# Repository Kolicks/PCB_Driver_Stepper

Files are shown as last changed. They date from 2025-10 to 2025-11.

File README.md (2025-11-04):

# 🌀 PCB_Driver_Stepper
**General Stepper Motor Driver Board**

## 🎬 Demo Video
[▶️ Watch Demo](Test_media/NEMA_Stepper.mp4)

<p align="center">
  <video src="https://github.com/user-attachments/assets/646c0d09-2157-4537-b24f-0206d356a9b6" width="600" controls></video>
  <br>
  <em>Demo NEMA Stepper</em>
</p>

---

## 📘 Overview
**PCB_Driver_Stepper** is a general-purpose stepper motor driver board designed in **KiCad 9**.  
This project was created to explore stepper motor control concepts, test design ideas from friends, and gain real experience with PCB design and STM32 microcontroller integration.  
It also represents my first complete project combining **hardware and STM32 firmware** using **STM32CubeIDE**.

<p align="center">
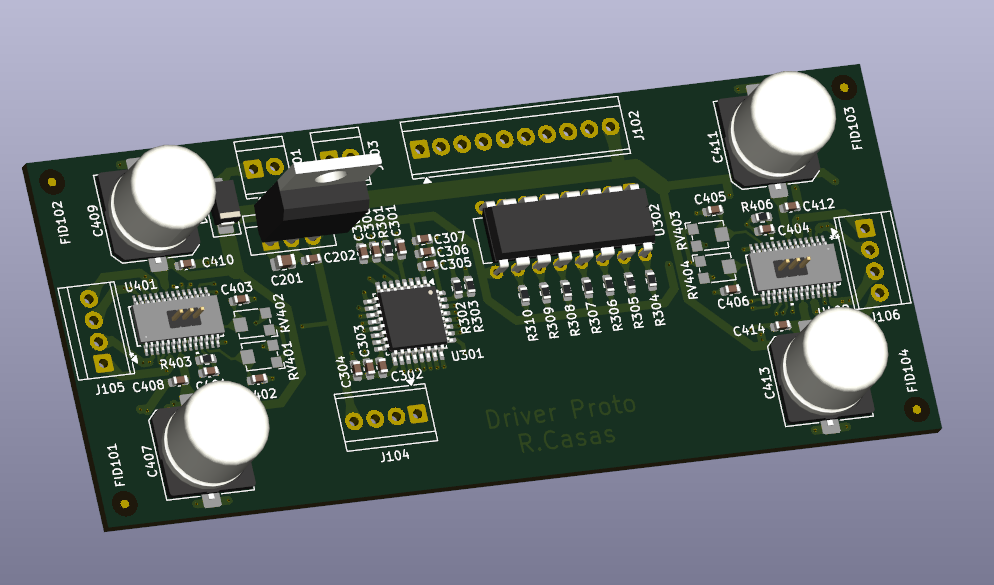
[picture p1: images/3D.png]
3D Render
  
  <br>
  <em>3D render of the finished PCB_Driver_Stepper board</em>
</p>

---

## ⚙️ General Information
- First real **KiCad 9** project.
- Implemented to test and validate several design ideas.
- Tested multiple implementations, including **ULN2002** and different **power dissipation** techniques.
- Designed with **4 layers**, though a **2-layer** version could be achieved.
- Typical **FR4 PCB**, **1.6 mm thickness**, standard prepreg stackup.
- Serves as my first practical integration within **STM32CubeIDE**, using **STM32F030K6T6** as the MCU.

<p align="center">
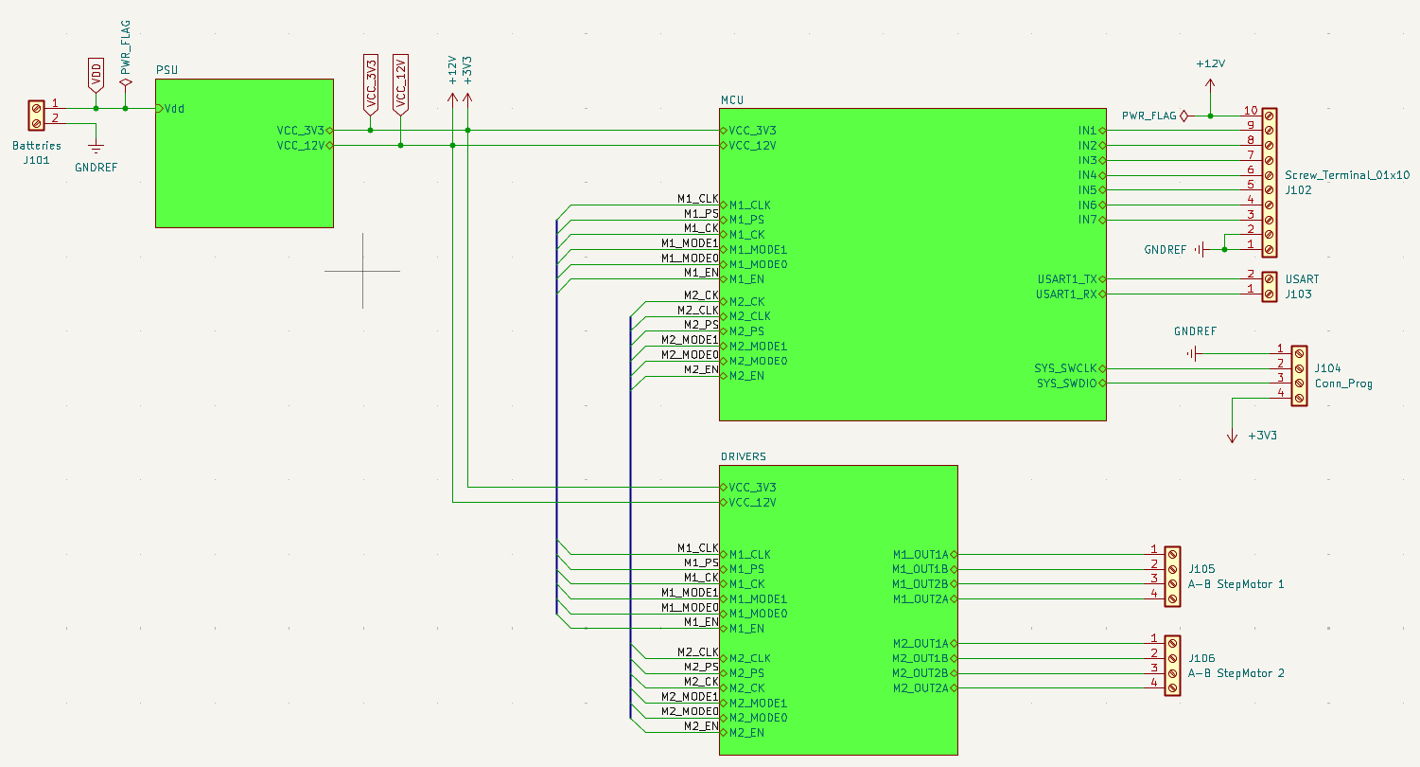
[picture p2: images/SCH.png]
Schematic
  
  <br>
  <em>Schematic, Block diagram (KiCad 9)</em>
</p>

---

## 🔧 Characteristics
- **Fully functional**, fabricated and tested successfully.
- Tested with **STEPPERONLINE NEMA 17** (2A, 59 N·cm) — achieves over **300 RPM** without load.
- Capable of controlling **two stepper motors** simultaneously.
- Supports up to **2 A per motor**, limited by drivers and onboard potentiometers.
- **Operating voltage:** 12 VDC to 24 VDC (ideal at 24 V).
- Requires **external cooling** (top and bottom) for continuous operation (Alimunium or Copper Radiators used in real test).
- Integrated with **ULN2002A** as input mode (tested and working).
- Uses **pin connectors under driver GND pads** to allow hand-soldering.
- Optional **Schottky diodes** for additional protection and power isolation.

<p align="center">
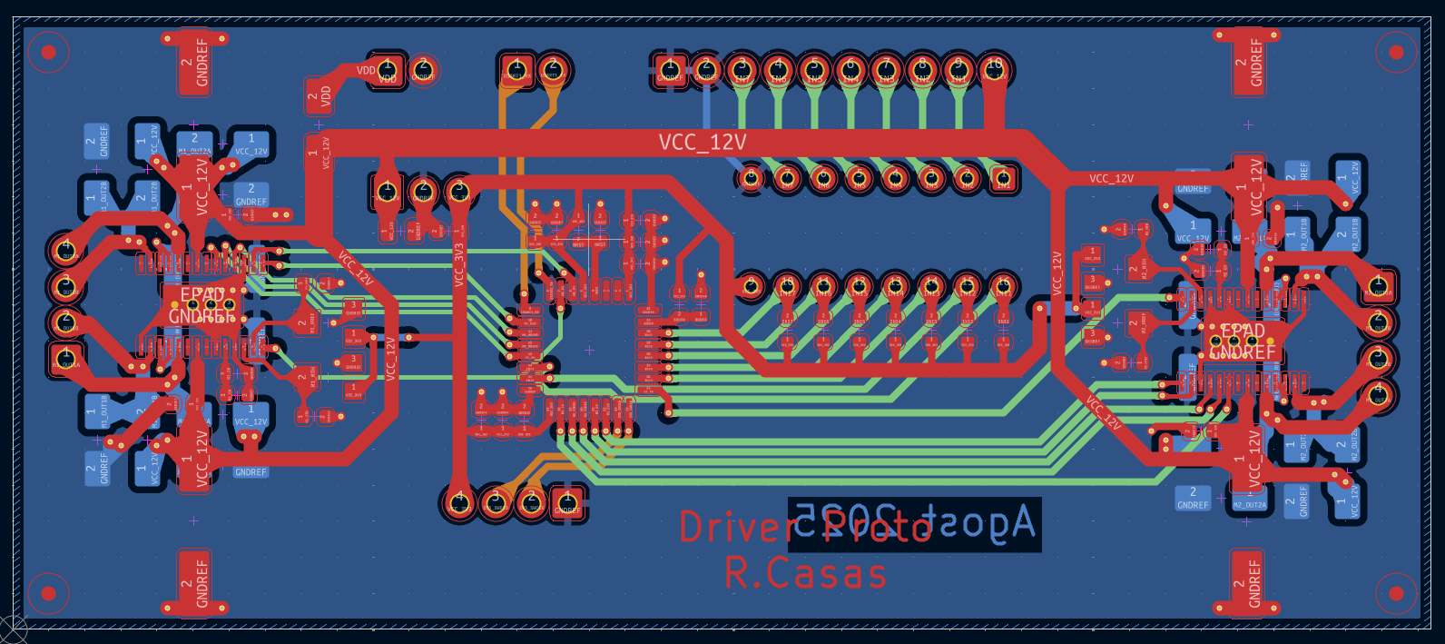
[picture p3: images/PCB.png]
  
  <br>
  <em>PCB layout design</em>
</p>

---

---

## 🔧 Panelization
- **Fully functional**, designed for **JLCPCB** fabrication process.  
- Created as an **exercise in PCB manufacturing and panelization design**.  
- Explored **V-cut (scoring) limitations**, fabrication tolerances, and how they affect mechanical integrity and assembly.  
- Observed potential **issues with scoring alignment and stress concentration** across panelized edges.  
- **Not required for this project**, as the board’s size and simplicity make panelization **unnecessary and potentially inefficient** for performance or cost.  

<p align="center">
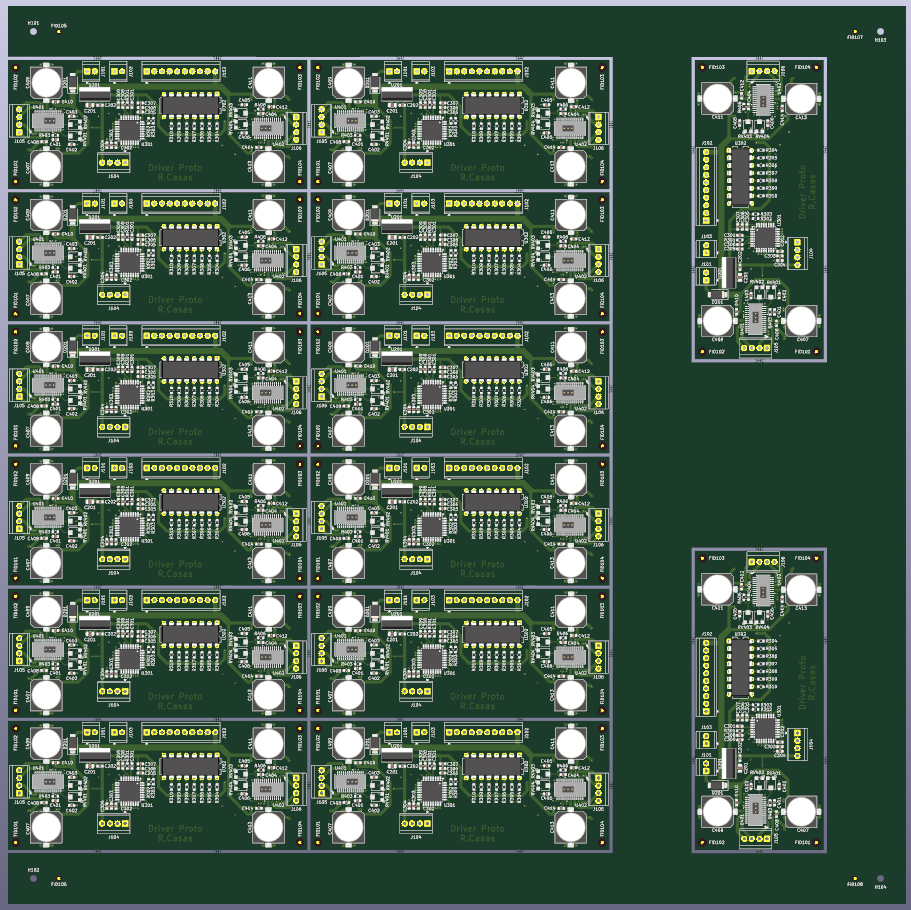
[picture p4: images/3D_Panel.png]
  
  <br>
  <em>Panel layout design</em>
</p>

---

## ⚠️ Known Issues / Notes
- Thermal pads on the **Rsense GND pads** restrict efficient heat dissipation.
- Ideally should maintain a **4-layer design** to ensure proper driver thermal management (as recommended in datasheets).
- Too many bypass Capacitors on the MCU.
- **No status LEDs** (e.g., Power or Fault indicators) currently included — consider adding in future revisions.

---

## 🧩 Files and Structure

<p align="center">
  <a href="https://github.com/Kolicks/PCB_Driver_Stepper" target="_blank">
    
  </a>
</p>

PCB_Driver_Stepper/

├── schematic/ # KiCad schematic files

├── pcb_layout/ # KiCad PCB layout files

├── gerbers/ # Gerber fabrication files

├── images/ # Rendered visuals (3D, SCH, PCB)

├── LICENSE # Hardware license (CERN-OHL-P v2.0)

└── README.md # Project documentation

---

## 📜 License
This hardware design is released under the **CERN Open Hardware License v2 – Permissive (CERN-OHL-P-2.0)**.  
You are free to use, modify, and distribute this design, provided that:
- The license is included with redistributions.
- Proper credit is given to the original author.

More info: https://cern-ohl.web.cern.ch/

---

## 👤 Author
**Project:** PCB_Driver_Stepper  
**Author:** Kolicks  
**Toolchain:** KiCad 9  
**Version:** 9.0  

---

## 🧱 Future Improvements

- **Thermal Design Enhancements:**  
  - Improve **thermal via networks** around driver ICs.  (Done in Panelization)
  - Add **dedicated copper areas** and optional heatsink support for improved temperature control.  (Done in Panelization)

- **User Feedback & Indicators:**  
  - Integrate **status LEDs** for power, enable, and fault signals.  
  - Add a **motor activity indicator** (blinking per step pulse).  

- **Electrical Optimization:**   
  - Consider **thicker copper (2 oz)** for better power handling.  
  - Optimize **Rsense trace routing** to reduce noise coupling.  (Done in Panelization)

- **Mechanical Improvements:**  
  - Adjust mounting hole positions for compatibility with standard enclosures.  
  - Add **labeling and silkscreen clarity** for easier connection identification.  

---

⭐ *If you find this project useful or educational, please consider starring the repository and sharing feedback!*

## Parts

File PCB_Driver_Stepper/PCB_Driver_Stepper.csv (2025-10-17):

Reference | Qty | Value | DNP | Exclude from BOM | Exclude from Board | Footprint | Datasheet
C201 | 1 | 330nF/50V |  |  |  | Capacitor_SMD:C_0805_2012Metric | ~
C202,C302,C303,C305,C306 | 5 | 100nF/10V |  |  |  | Capacitor_SMD:C_0603_1608Metric | ~
C301 | 1 | 100nF |  |  |  | Capacitor_SMD:C_0603_1608Metric | ~
C304,C307,C309 | 3 | 4.7uF/10V |  |  |  | Capacitor_SMD:C_0603_1608Metric | ~
C308 | 1 | 10nF/10V |  |  |  | Capacitor_SMD:C_0603_1608Metric | ~
C401,C402,C403,C404,C405,C406 | 6 | 1000pF/10V |  |  |  | Capacitor_SMD:C_0603_1608Metric | ~
C407,C409,C411,C413 | 4 | 470uF/50V |  |  |  | Capacitor_SMD:C_Elec_10x10.2
C408,C410,C412,C414 | 4 | 100nF/50V |  |  |  | Capacitor_SMD:C_0603_1608Metric | ~
D201 | 1 | 1N4001 |  |  |  | Diode_SMD:D_SMA | http://www.vishay.com/docs/88503/1n4001.pdf
D401,D402,D403,D404,D405,D406,D407,D408,D409,D410,D411,D412,D413,D414,D415,D416 | 16 | SK36A |  |  |  | Diode_SMD:D_SMA | ~
FID101,FID102,FID103,FID104 | 4 | Fiducial |  | Excluded from BOM |  | Fiducial:Fiducial_1mm_Mask3mm | ~
J101 | 1 | Batteries |  |  |  | TerminalBlock_TE-Connectivity:TerminalBlock_TE_282834-2_1x02_P2.54mm_Horizontal | ~
J102 | 1 | Screw_Terminal_01x10 |  |  |  | TerminalBlock_TE-Connectivity:TerminalBlock_TE_1-282834-0_1x10_P2.54mm_Horizontal | ~
J103 | 1 | USART |  |  |  | TerminalBlock_TE-Connectivity:TerminalBlock_TE_282834-2_1x02_P2.54mm_Horizontal | ~
J104 | 1 | Conn_Prog |  |  |  | TerminalBlock_TE-Connectivity:TerminalBlock_TE_282834-4_1x04_P2.54mm_Horizontal | ~
J105 | 1 | A-B StepMotor 1 |  |  |  | TerminalBlock_TE-Connectivity:TerminalBlock_TE_282834-4_1x04_P2.54mm_Horizontal | ~
J106 | 1 | A-B StepMotor 2 |  |  |  | TerminalBlock_TE-Connectivity:TerminalBlock_TE_282834-4_1x04_P2.54mm_Horizontal | ~
J107 | 1 | ThermalDriv1 |  |  |  | Prova_Ricard_Driver_footprint:PinHeader_1x03_P1.27mm_Vertical | ~
J108 | 1 | ThermalDriv2 |  |  |  | Prova_Ricard_Driver_footprint:PinHeader_1x03_P1.27mm_Vertical | ~
R301,R302,R303 | 3 | 100k |  |  |  | Resistor_SMD:R_0603_1608Metric | ~
R304,R305,R306,R307,R308,R309,R310 | 7 | 10k |  |  |  | Resistor_SMD:R_0603_1608Metric | ~
R401,R402,R404,R405 | 4 | 0.25R |  |  |  | Resistor_SMD:R_2512_6332Metric | ~
R403,R406 | 2 | 39k |  |  |  | Resistor_SMD:R_0603_1608Metric | ~
RV401,RV402,RV403,RV404 | 4 | R_Potentiometer |  |  |  | Potentiometer_SMD:Potentiometer_Bourns_TC33X_Vertical | ~
U201 | 1 | LM7833_TO220 |  |  |  | Package_TO_SOT_THT:TO-220-3_Vertical | https://www.onsemi.cn/PowerSolutions/document/MC7800-D.PDF
U301 | 1 | STM32F030K6Tx |  |  |  | Package_QFP:LQFP-32_7x7mm_P0.8mm | https://www.st.com/resource/en/datasheet/stm32f030k6.pdf
U302 | 1 | ULN2002A |  |  |  | Package_DIP:DIP-16_W7.62mm | http://www.ti.com/lit/ds/symlink/uln2003a.pdf
U401,U402 | 2 | BD63521EFV-E2 |  |  |  | HTSSOP-B28_ROM:HTSSOP-B28_ROM | BD63521EFV-E2

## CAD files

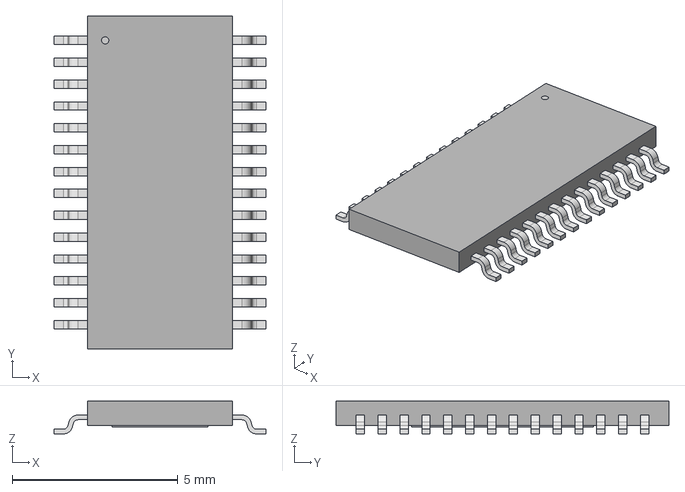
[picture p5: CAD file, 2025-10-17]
PCB_Driver_Stepper/Symbol_Footprint/MBRS360T3G/HTSSOP-B28_ROM.step
6.40 x 10.1 x 0.993 mm

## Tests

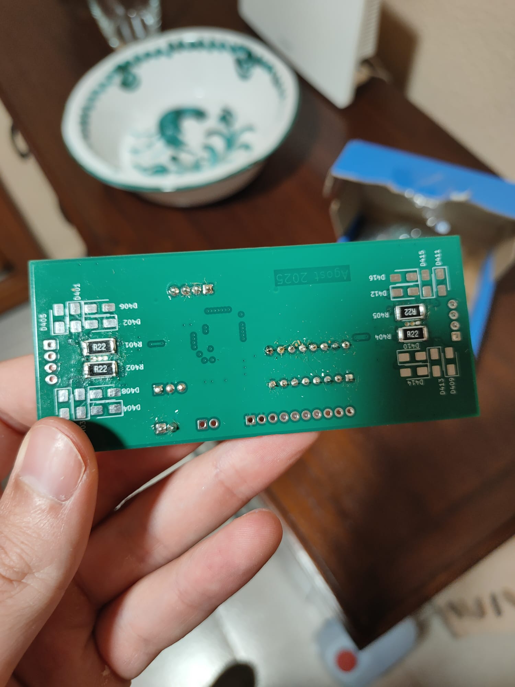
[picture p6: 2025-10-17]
Test_media/Bottom_view.jpeg

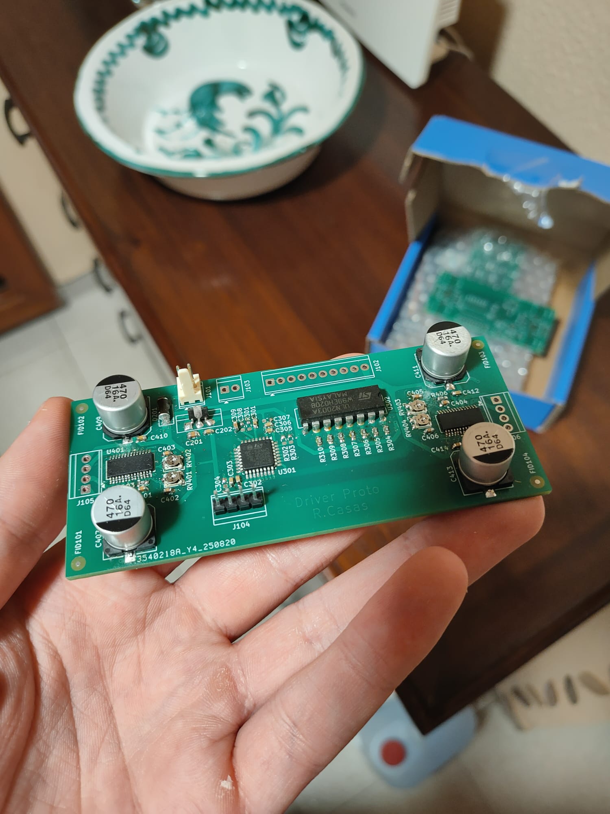
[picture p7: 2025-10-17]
Test_media/TOP_view.jpeg

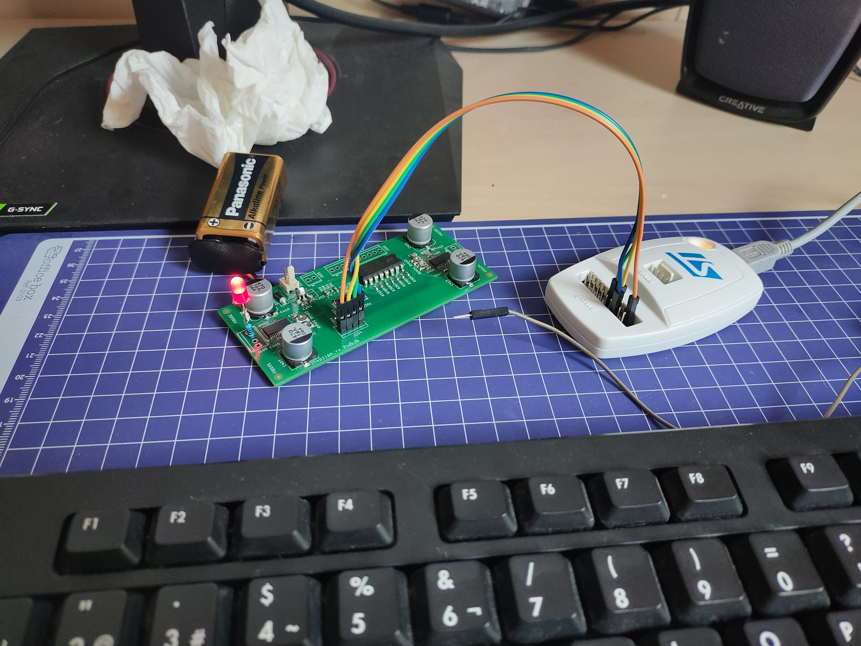
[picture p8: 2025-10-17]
Test_media/Programming.jpeg

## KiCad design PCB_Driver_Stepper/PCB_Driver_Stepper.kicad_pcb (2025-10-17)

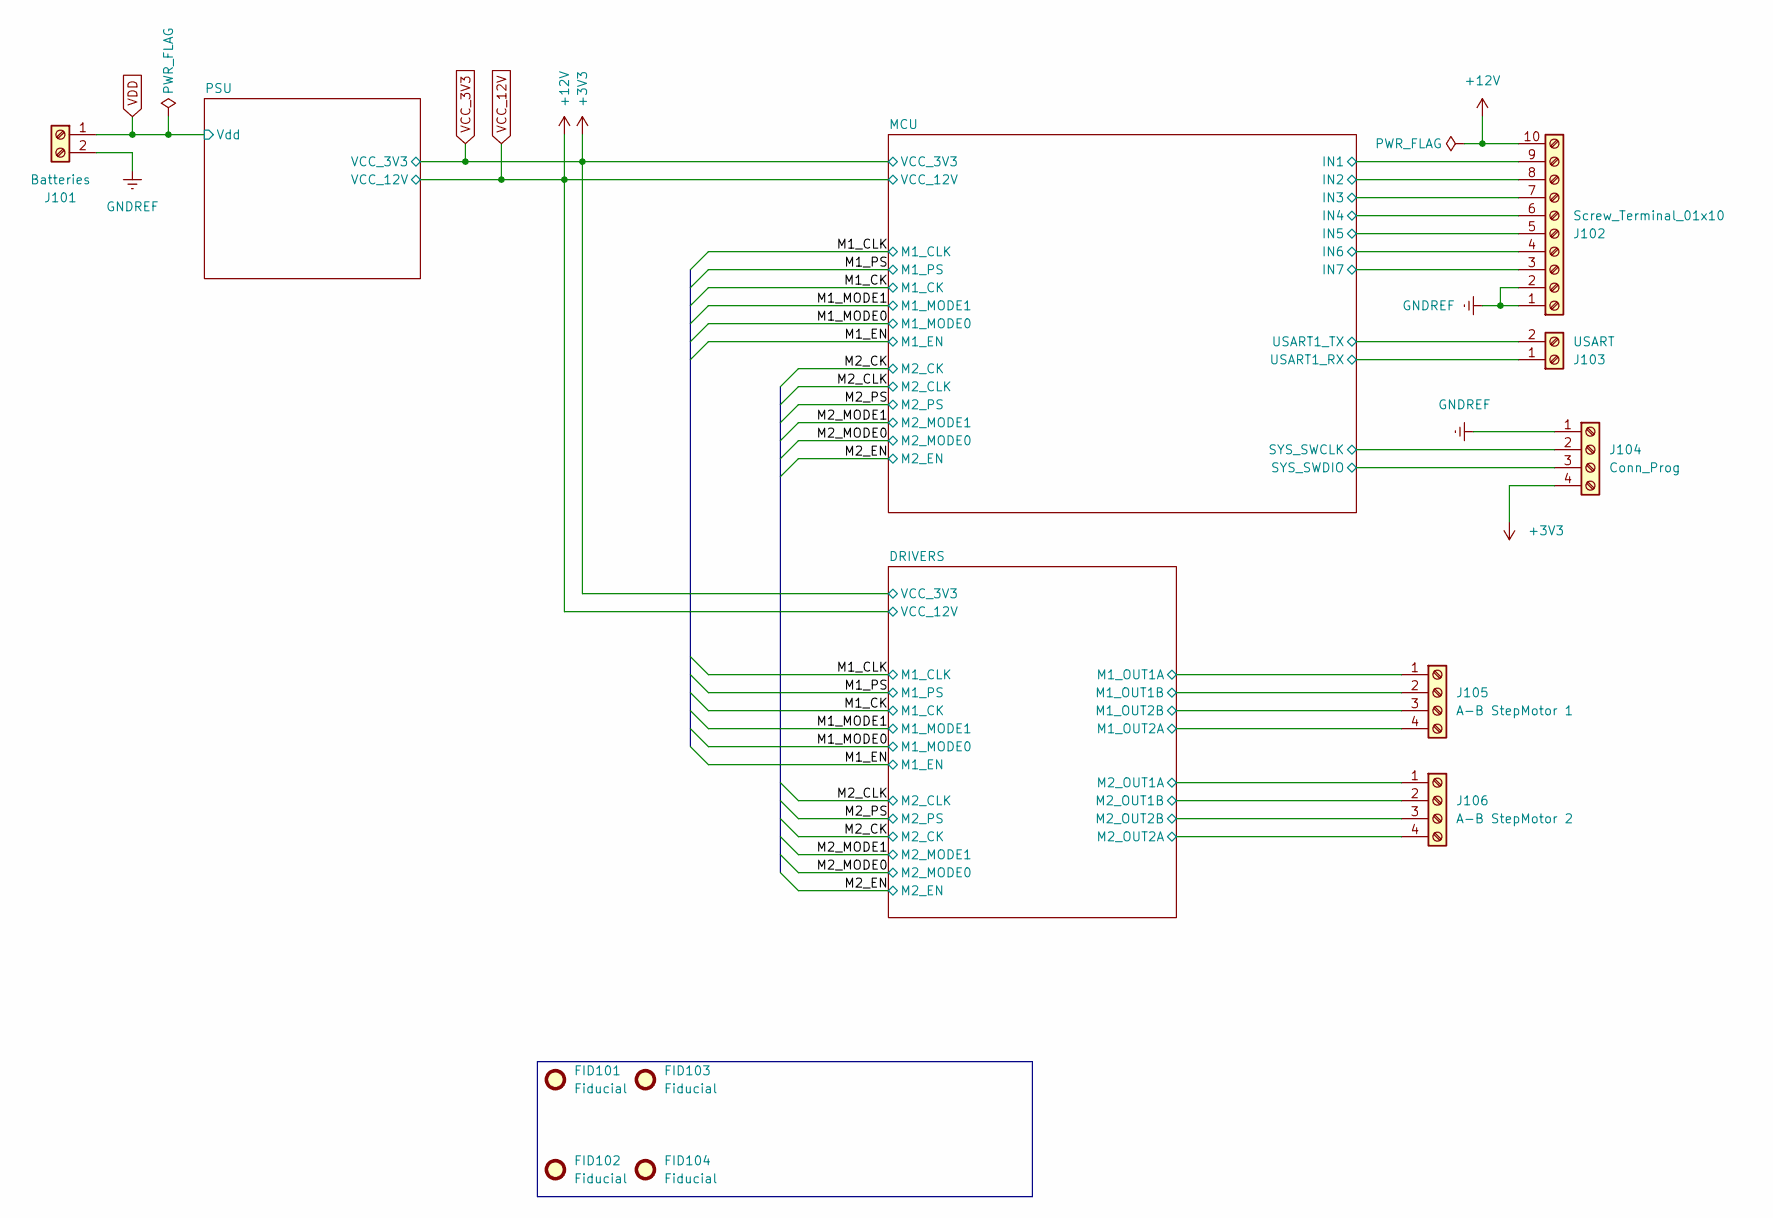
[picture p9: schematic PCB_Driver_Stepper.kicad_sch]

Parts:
FID101, FID102, FID103, FID104: Fiducial; Fiducial_1mm_Mask3mm
J101: Batteries; TerminalBlock_TE_282834-2_1x02_P2.54mm_Horizontal
J102: Screw_Terminal_01x10; TerminalBlock_TE_1-282834-0_1x10_P2.54mm_Horizontal
J103: USART; TerminalBlock_TE_282834-2_1x02_P2.54mm_Horizontal
J104: Conn_Prog; TerminalBlock_TE_282834-4_1x04_P2.54mm_Horizontal
J105: A-B StepMotor 1; TerminalBlock_TE_282834-4_1x04_P2.54mm_Horizontal
J106: A-B StepMotor 2; TerminalBlock_TE_282834-4_1x04_P2.54mm_Horizontal

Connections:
/DRIVERS/M1_OUT1A: J105.1; also elsewhere on the board
/DRIVERS/M1_OUT1B: J105.2; also elsewhere on the board
/DRIVERS/M1_OUT2A: J105.4; also elsewhere on the board
/DRIVERS/M1_OUT2B: J105.3; also elsewhere on the board
/DRIVERS/M2_OUT1A: J106.1; also elsewhere on the board
/DRIVERS/M2_OUT1B: J106.2; also elsewhere on the board
/DRIVERS/M2_OUT2A: J106.4; also elsewhere on the board
/DRIVERS/M2_OUT2B: J106.3; also elsewhere on the board
/MCU/IN1: J102.9; also elsewhere on the board
/MCU/IN2: J102.8; also elsewhere on the board
/MCU/IN3: J102.7; also elsewhere on the board
/MCU/IN4: J102.6; also elsewhere on the board
/MCU/IN5: J102.5; also elsewhere on the board
/MCU/IN6: J102.4; also elsewhere on the board
/MCU/IN7: J102.3; also elsewhere on the board
/MCU/SYS_SWCLK: J104.2; also elsewhere on the board
/MCU/SYS_SWDIO: J104.3; also elsewhere on the board
/MCU/USART1_RX: J103.1; also elsewhere on the board
/MCU/USART1_TX: J103.2; also elsewhere on the board
GNDREF: J101.2, J102.1, J102.2, J104.1; also elsewhere on the board
VCC_3V3: J104.4; also elsewhere on the board
VCC_12V: J102.10; also elsewhere on the board
VDD: J101.1; also elsewhere on the board

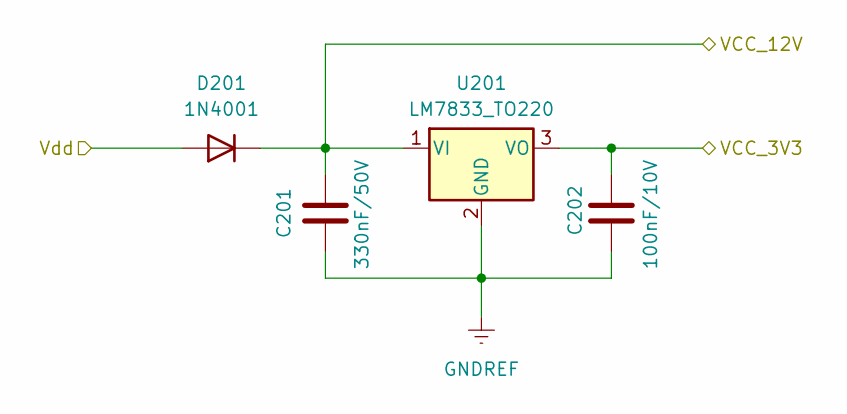
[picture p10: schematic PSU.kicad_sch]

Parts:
C201: 330nF/50V; C_0805_2012Metric
C202: 100nF/10V; C_0603_1608Metric
D201: 1N4001; D_SMA
U201: LM7833_TO220; TO-220-3_Vertical

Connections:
GNDREF: C201.2, C202.2, U201.2 (GND); also elsewhere on the board
VCC_3V3: C202.1, U201.3 (VO); also elsewhere on the board
VCC_12V: C201.1, D201.1 (K), U201.1 (VI); also elsewhere on the board
VDD: D201.2 (A); also elsewhere on the board

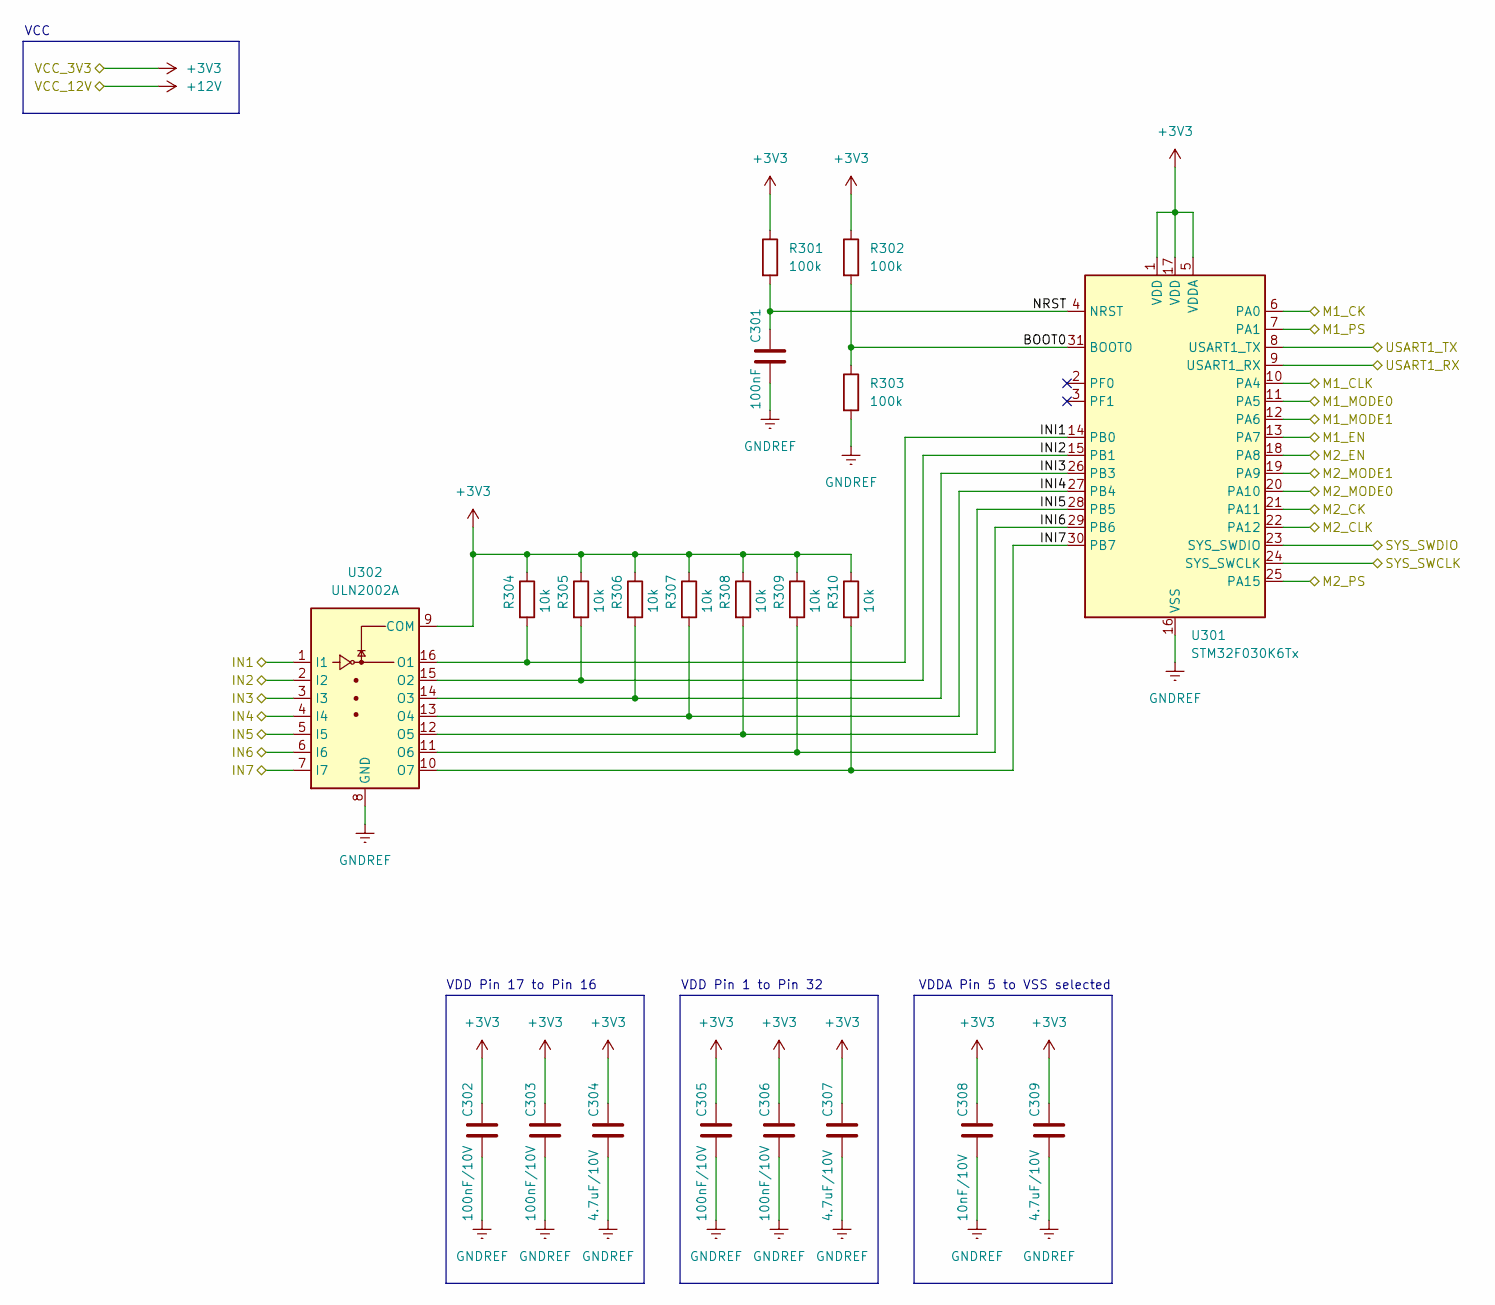
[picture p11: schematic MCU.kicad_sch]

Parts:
C301: 100nF; C_0603_1608Metric
C302, C303, C305, C306: 100nF/10V; C_0603_1608Metric
C304, C307, C309: 4.7uF/10V; C_0603_1608Metric
C308: 10nF/10V; C_0603_1608Metric
R301, R302, R303: 100k; R_0603_1608Metric
R304, R305, R306, R307, R308, R309, R310: 10k; R_0603_1608Metric
U301: STM32F030K6Tx; LQFP-32_7x7mm_P0.8mm
U302: ULN2002A; DIP-16_W7.62mm

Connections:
/M1_CK: U301.6 (PA0); also elsewhere on the board
/M1_CLK: U301.10 (PA4); also elsewhere on the board
/M1_EN: U301.13 (PA7); also elsewhere on the board
/M1_MODE0: U301.11 (PA5); also elsewhere on the board
/M1_MODE1: U301.12 (PA6); also elsewhere on the board
/M1_PS: U301.7 (PA1); also elsewhere on the board
/M2_CK: U301.21 (PA11); also elsewhere on the board
/M2_CLK: U301.22 (PA12); also elsewhere on the board
/M2_EN: U301.18 (PA8); also elsewhere on the board
/M2_MODE0: U301.20 (PA10); also elsewhere on the board
/M2_MODE1: U301.19 (PA9); also elsewhere on the board
/M2_PS: U301.25 (PA15); also elsewhere on the board
/MCU/BOOT0: R302.2, R303.1, U301.31 (BOOT0)
/MCU/IN1: U302.1 (I1); also elsewhere on the board
/MCU/IN2: U302.2 (I2); also elsewhere on the board
/MCU/IN3: U302.3 (I3); also elsewhere on the board
/MCU/IN4: U302.4 (I4); also elsewhere on the board
/MCU/IN5: U302.5 (I5); also elsewhere on the board
/MCU/IN6: U302.6 (I6); also elsewhere on the board
/MCU/IN7: U302.7 (I7); also elsewhere on the board
/MCU/INI1: R304.2, U301.14 (PB0), U302.16 (O1)
/MCU/INI2: R305.2, U301.15 (PB1), U302.15 (O2)
/MCU/INI3: R306.2, U301.26 (PB3), U302.14 (O3)
/MCU/INI4: R307.2, U301.27 (PB4), U302.13 (O4)
/MCU/INI5: R308.2, U301.28 (PB5), U302.12 (O5)
/MCU/INI6: R309.2, U301.29 (PB6), U302.11 (O6)
/MCU/INI7: R310.2, U301.30 (PB7), U302.10 (O7)
/MCU/NRST: C301.1, R301.2, U301.4 (NRST)
/MCU/SYS_SWCLK: U301.24 (SYS_SWCLK); also elsewhere on the board
/MCU/SYS_SWDIO: U301.23 (SYS_SWDIO); also elsewhere on the board
/MCU/USART1_RX: U301.9 (USART1_RX); also elsewhere on the board
/MCU/USART1_TX: U301.8 (USART1_TX); also elsewhere on the board
GNDREF: C301.2, C302.2, C303.2, C304.2, C305.2, C306.2, C307.2, C308.2, C309.2, R303.2, U301.16 (VSS), U301.32 (VSS), U302.8 (GND); also elsewhere on the board
VCC_3V3: C302.1, C303.1, C304.1, C305.1, C306.1, C307.1, C308.1, C309.1, R301.1, R302.1, R304.1, R305.1, R306.1, R307.1, R308.1, R309.1, R310.1, U301.1 (VDD), U301.5 (VDDA), U301.17 (VDD), U302.9 (COM); also elsewhere on the board

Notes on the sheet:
VDDA Pin 5 to VSS selected
VDD Pin 1 to Pin 32
VDD Pin 17 to Pin 16
VCC

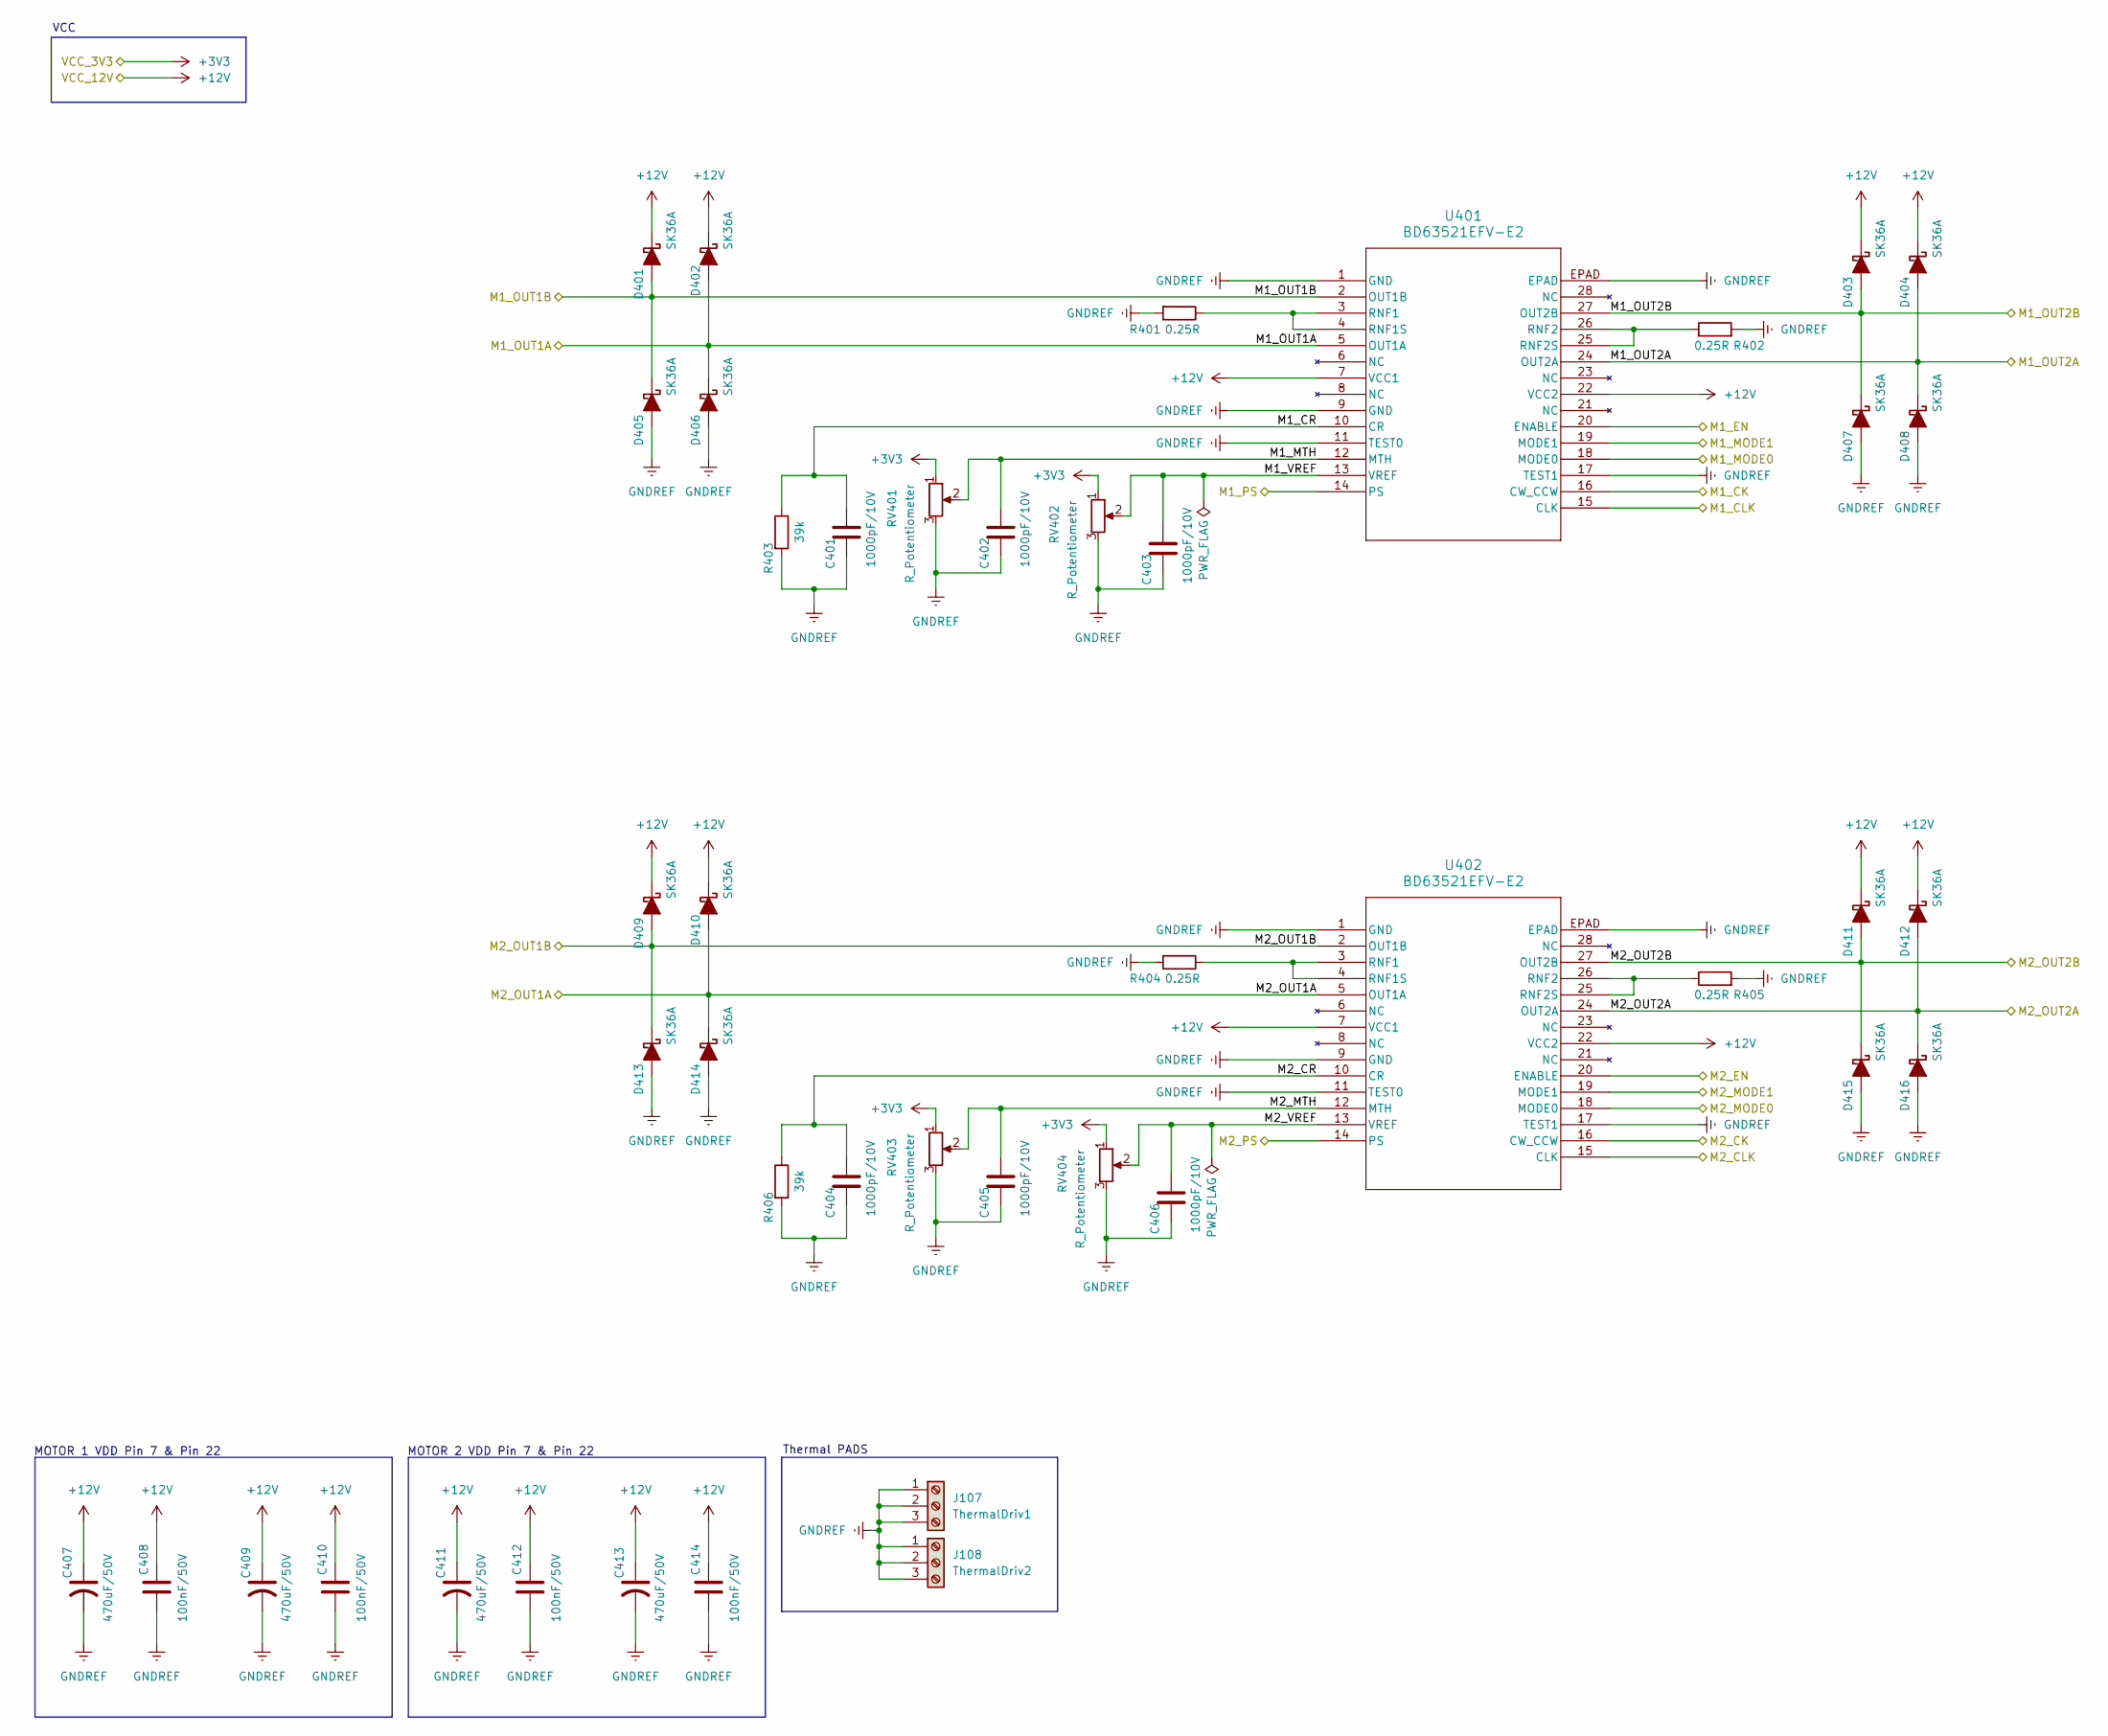
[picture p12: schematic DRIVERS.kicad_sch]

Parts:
C401, C402, C403, C404, C405, C406: 1000pF/10V; C_0603_1608Metric
C407, C409, C411, C413: 470uF/50V; C_Elec_10x10.2; Voltage 50V
C408, C410, C412, C414: 100nF/50V; C_0603_1608Metric; Voltage 50V
D401, D402, D403, D404, D405, D406, D407, D408, D409, D410, D411, D412, D413, D414, D415, D416: SK36A; D_SMA
J107: ThermalDriv1; PinHeader_1x03_P1.27mm_Vertical
J108: ThermalDriv2; PinHeader_1x03_P1.27mm_Vertical
R401, R402, R404, R405: 0.25R; R_2512_6332Metric
R403, R406: 39k; R_0603_1608Metric
RV401, RV402, RV403, RV404: R_Potentiometer; Potentiometer_Bourns_TC33X_Vertical
U401, U402: BD63521EFV-E2; HTSSOP-B28_ROM

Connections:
/DRIVERS/M1_CR: C401.1, R403.1, U401.10 (CR)
/DRIVERS/M1_MTH: C402.1, RV401.2, U401.12 (MTH)
/DRIVERS/M1_OUT1A: D402.2 (A), D406.1 (K), U401.5 (OUT1A); also elsewhere on the board
/DRIVERS/M1_OUT1B: D401.2 (A), D405.1 (K), U401.2 (OUT1B); also elsewhere on the board
/DRIVERS/M1_OUT2A: D404.2 (A), D408.1 (K), U401.24 (OUT2A); also elsewhere on the board
/DRIVERS/M1_OUT2B: D403.2 (A), D407.1 (K), U401.27 (OUT2B); also elsewhere on the board
/DRIVERS/M1_VREF: C403.1, RV402.2, U401.13 (VREF)
/DRIVERS/M2_CR: C404.1, R406.1, U402.10 (CR)
/DRIVERS/M2_MTH: C405.1, RV403.2, U402.12 (MTH)
/DRIVERS/M2_OUT1A: D410.2 (A), D414.1 (K), U402.5 (OUT1A); also elsewhere on the board
/DRIVERS/M2_OUT1B: D409.2 (A), D413.1 (K), U402.2 (OUT1B); also elsewhere on the board
/DRIVERS/M2_OUT2A: D412.2 (A), D416.1 (K), U402.24 (OUT2A); also elsewhere on the board
/DRIVERS/M2_OUT2B: D411.2 (A), D415.1 (K), U402.27 (OUT2B); also elsewhere on the board
/DRIVERS/M2_VREF: C406.1, RV404.2, U402.13 (VREF)
/M1_CK: U401.16 (CW_CCW); also elsewhere on the board
/M1_CLK: U401.15 (CLK); also elsewhere on the board
/M1_EN: U401.20 (ENABLE); also elsewhere on the board
/M1_MODE0: U401.18 (MODE0); also elsewhere on the board
/M1_MODE1: U401.19 (MODE1); also elsewhere on the board
/M1_PS: U401.14 (PS); also elsewhere on the board
/M2_CK: U402.16 (CW_CCW); also elsewhere on the board
/M2_CLK: U402.15 (CLK); also elsewhere on the board
/M2_EN: U402.20 (ENABLE); also elsewhere on the board
/M2_MODE0: U402.18 (MODE0); also elsewhere on the board
/M2_MODE1: U402.19 (MODE1); also elsewhere on the board
/M2_PS: U402.14 (PS); also elsewhere on the board
GNDREF: C401.2, C402.2, C403.2, C404.2, C405.2, C406.2, C407.2, C408.2, C409.2, C410.2, C411.2, C412.2, C413.2, C414.2, D405.2 (A), D406.2 (A), D407.2 (A), D408.2 (A), D413.2 (A), D414.2 (A), D415.2 (A), D416.2 (A), J107.1, J107.2, J107.3, J108.1, J108.2, J108.3, R401.2, R402.2, R403.2, R404.2, R405.2, R406.2, RV401.3, RV402.3, RV403.3, RV404.3, U401.1 (GND), U401.9 (GND), U401.11 (TEST0), U401.17 (TEST1), U401.EPAD, U402.1 (GND), U402.9 (GND), U402.11 (TEST0), U402.17 (TEST1), U402.EPAD; also elsewhere on the board
unnamed: R401.1, U401.3 (RNF1), U401.4 (RNF1S)
unnamed: R402.1, U401.25 (RNF2S), U401.26 (RNF2)
unnamed: R404.1, U402.3 (RNF1), U402.4 (RNF1S)
unnamed: R405.1, U402.25 (RNF2S), U402.26 (RNF2)
VCC_3V3: RV401.1, RV402.1, RV403.1, RV404.1; also elsewhere on the board
VCC_12V: C407.1, C408.1, C409.1, C410.1, C411.1, C412.1, C413.1, C414.1, D401.1 (K), D402.1 (K), D403.1 (K), D404.1 (K), D409.1 (K), D410.1 (K), D411.1 (K), D412.1 (K), U401.7 (VCC1), U401.22 (VCC2), U402.7 (VCC1), U402.22 (VCC2); also elsewhere on the board

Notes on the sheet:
MOTOR 2 VDD Pin 7 & Pin 22
VCC
MOTOR 1 VDD Pin 7 & Pin 22
Thermal PADS

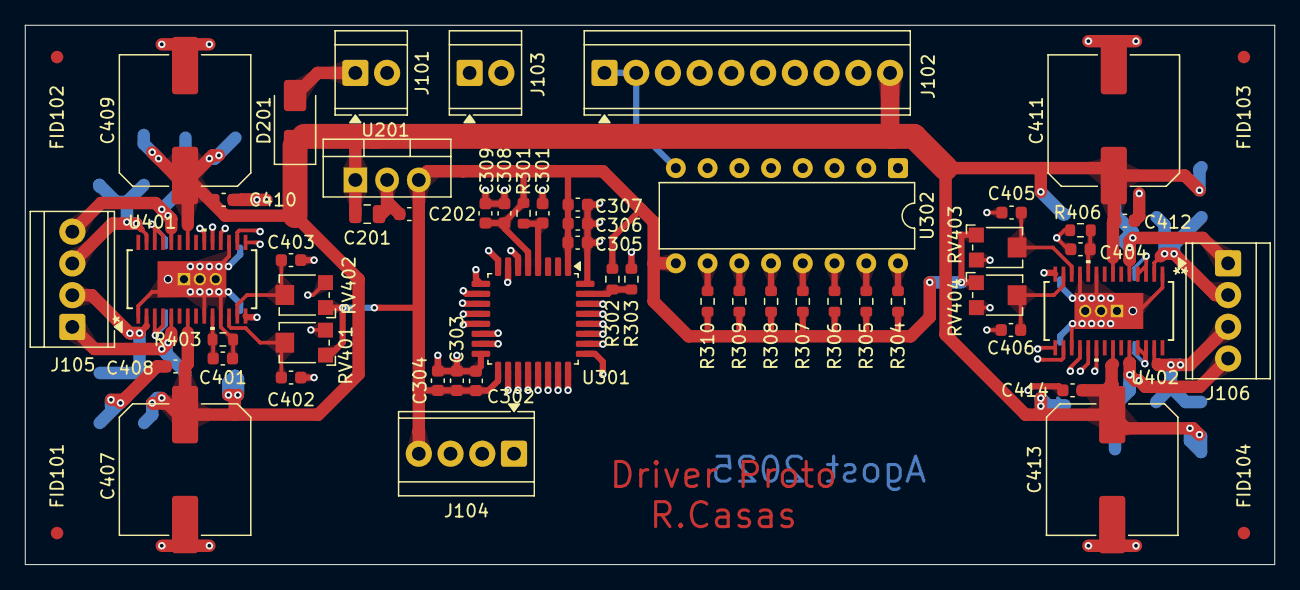
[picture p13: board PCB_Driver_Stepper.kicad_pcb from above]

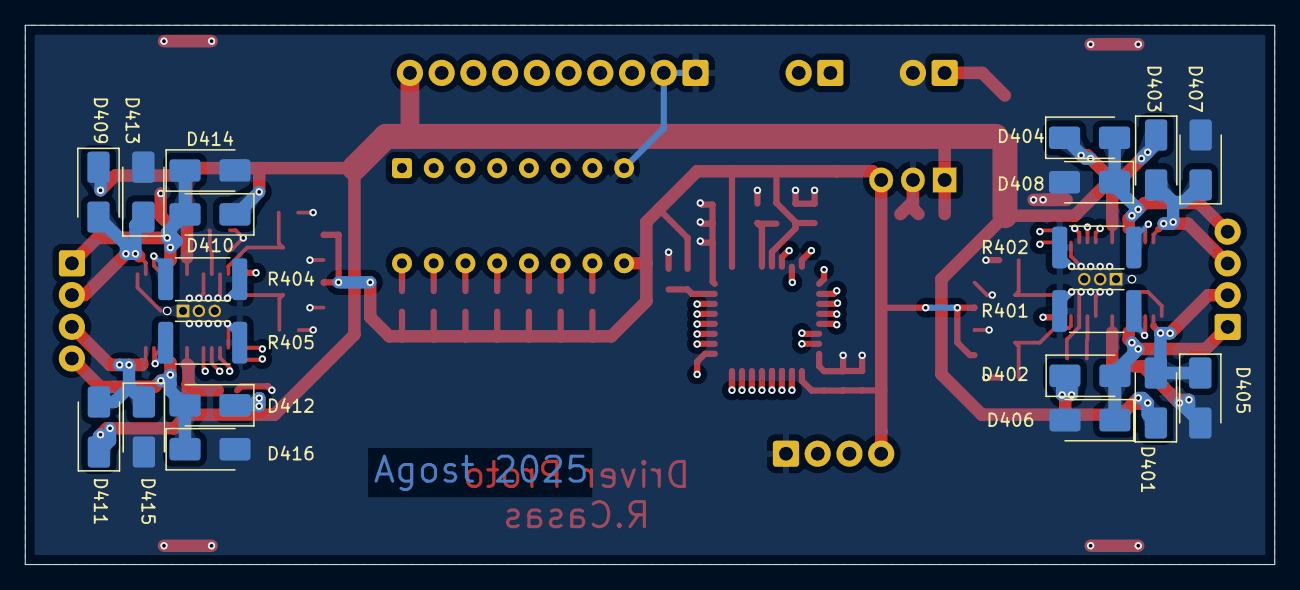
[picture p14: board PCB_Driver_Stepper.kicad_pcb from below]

Board: 4 copper layers, 100.0 x 43.2 mm, 79 parts (20 on the bottom side), 54 nets.

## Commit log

2025-10-17 Revise README for PCB_Driver_Stepper project
    Updated README.md to enhance project description and structure.
2025-10-17 All files
    [DRIVERS.kicad_sch, HTSSOP-B28_ROM.step, MCU.kicad_sch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]
2025-11-04 Add files via upload
    Panelization of the project:
    Also som other changes on the PCB:
    - Solid pads for rsense Ground.
    - Added planes of GND on layers 2 & 3 for thermal relief.
